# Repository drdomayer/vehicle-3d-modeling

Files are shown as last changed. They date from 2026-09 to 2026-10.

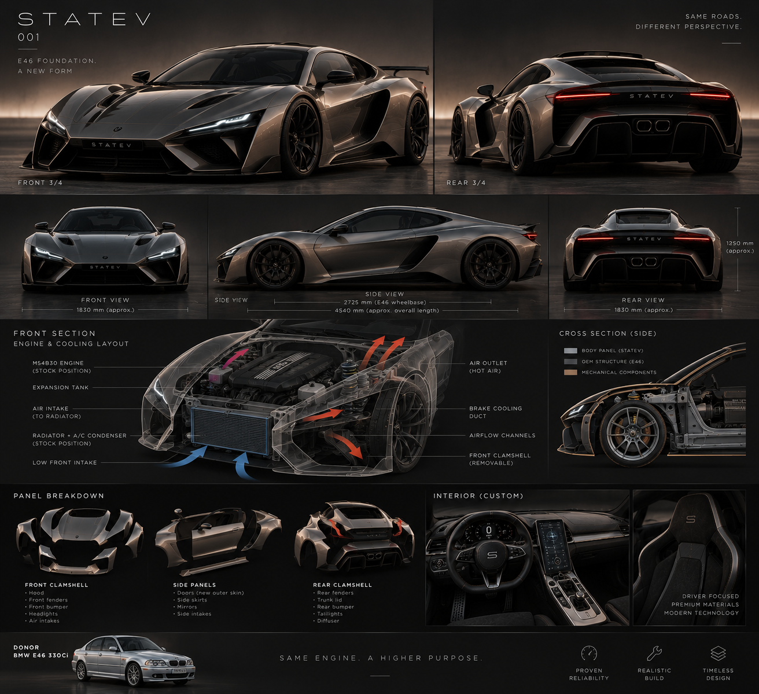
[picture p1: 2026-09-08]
07_PRESENTATION/references/ref-01-e46-supercar-concept-REJECTED-donor.png

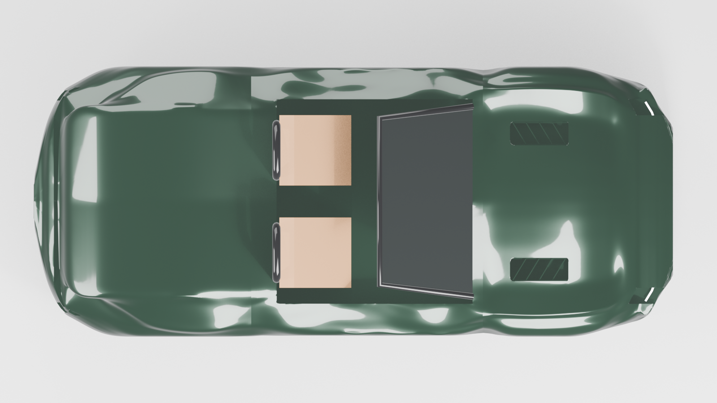
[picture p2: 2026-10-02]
04_ENGINEERING/statev_v01/review/rv_glossy_clean_top.png

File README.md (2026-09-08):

# vehicle-3d-modeling — STATEV 001

Boutique one-off sports car: new composite body + interior on a Porsche Boxster 986 base.

Start here:
1. `CLAUDE.md` — project memory (decisions, constraints, status). Claude Code reads it automatically.
2. `docs/` — brief, hardpoints, design direction, lighting/legal, manufacturing, budget, roadmap, tools, decision log.
3. `07_PRESENTATION/references/` — renders. `CHOSEN` = target, `REJECTED` = history.
4. `01_CAD/scripts/cage_986.py` — regenerable hardpoint cage for Blender.

Folders:
```
00_SCAN/          scans of the donor (raw, cleaned)
01_CAD/           scripts, STEP/IGES exports
02_DESIGN/        .blend files: exterior / interior / lighting
03_PRINT/         STL/3MF split for the printer + exploded-view PDFs
04_ENGINEERING/   clearance, tyre envelope, roof fold path, lamp positions
05_MOULD/         (only if a kit is made)
06_COMPOSITE/     layup notes, materials
07_PRESENTATION/  references, renders, branding
docs/             project documentation
```

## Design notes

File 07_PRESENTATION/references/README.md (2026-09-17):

# Reference renders (AI-generated, ChatGPT)

| File | What | Status |
|---|---|---|
| ref-01-e46-supercar-concept-REJECTED-donor.png | First STATEV 001 infographic on a claimed BMW E46 base. Mid-engine Huracán-type silhouette — impossible on E46. Kept for design language (front mask, light blade, panel breakdown, interior direction) | donor REJECTED, look = inspiration only |
| ref-02-z4-e86-front-engine-gt-REJECTED.jpeg | Front-engine GT on BMW Z4 E86 with Koenigsegg-inspired rear. Owner: "too Z4, no individuality" | REJECTED |
| ref-03-986-roadster-v1.png | First 986-based STATEV 001, soft surfacing | superseded ("boring") |
| ref-04-986-roadster-v2-soft-top-closed.png | v1 with closed soft top and raised deck | superseded; useful for the deck/roof integration idea |
| ref-05-986-futuristic-v3-CHOSEN.png | Radical futuristic direction (Czinger/Zenvo/Gemera language) on 986 hardpoints | superseded as the measuring target by ref-09 |
| ref-09-statev-001-four-view-CURRENT-TARGET.png | Four-view set of the same car — side, top, front, rear, plus three detail close-ups. Asked for in docs/18 | **CURRENT TARGET.** Side and top are measurable; front and rear are NOT — they show the cockpit interior, so the camera is above the car and their heights are foreshortened |

Rules: numbers in AI infographics are invented — ignore them. Renders show
wheels/clearance that are not road legal; the cage script has the real values.

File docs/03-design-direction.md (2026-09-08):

# 03 — Design direction

Референция: `07_PRESENTATION/references/ref-05-986-futuristic-v3-CHOSEN.png`.
Всички други рендери са история или отхвърлени варианти — виж README там.

## Език

Радикално футуристичен hypercar език: Czinger 21C, Zenvo Aurora, Koenigsegg
Gemera, Aston Martin Valkyrie. Не retro, не Porsche-подобно, без меки
повърхности. Собствен STATEV signature — не копие на никоя марка.

## Елементи (от ref-05)

**Отпред**
- Изключително нисък wedge нос; тънка светеща линия по цялата ширина (DRL) над
  голяма отворена уста към радиаторите.
- Плаващи предни калници с отворен канал зад всяко колело (изход на горещ въздух
  от радиаторите — функционален).
- Сплитер с вертикални елементи.

**Отстрани**
- Дълбок канал, врязан във вратата, който води към функционалния intake пред
  задното колело, с вертикално острие (blade).
- Наслоени панели с видимо "негативно пространство" между тях.
- Прагове със стъпка и черен долен канал.

**Отзад**
- Две високи аеро перки зад roll hoops вместо меки гърбици; преливат в
  повдигнат deck с открити ламели над двигателя.
- Затвореният мек покрив ляга между перките.
- Отворена задна структура: тънка обвивка над видим дифузьорен тунел, централен
  двоен ауспух високо в опашката, ултратънки L-образни светлинни остриета.

**Общо**
- Тъмно металик зелено, бронзови 19" джанти с реална странична стена на гумата,
  тан кожа, клирънс 120 mm.
- Всеки отвор е функционален. Без декоративни вентилации.

## Покрив и deck — правила

- Мекият покрив остава OEM механизъм. Не се пипа.
- Deck-ът се вдига/удължава така, че линията стъкло → покрив → задно стъкло →
  deck е една непрекъсната наклонена линия без стъпало, когато покривът е
  затворен.
- Deck-ът остава под долния ръб на задното стъкло на покрива (видимост).
- Всичко зад roll hoops се отваря или е част от капака (достъп до двигателя).
- Пътят на сгъване на покрива и clamshell-а се проверяват в CAD преди дизайн на
  deck-а.

## Правила за фуги

Ръбовете на новите панели лягат само върху съществуващи линии: фуга на
вратата, долен ръб на прага, отвор на стопа, фуга на задния капак, ръб под
roll-hoop капака. Където няма естествена фуга (горен ръб на рамото) — flush
секция с изрязана OEM обшивка и фланец.

## Как се прави рендер за референция (ChatGPT/Gemini)

Референция [ref-05] + 986 профил. Винаги: "mid-engine, cabin far forward,
keep windshield frame/rake, twin roll hoops, door cut lines, wheel centres,
wheelbase 2415 mm, side intake ahead of rear wheel functional, 19-inch wheels
with realistic sidewall, 120 mm ground clearance, no text overlays". Първо
профил, после 3/4. Числата в AI инфографиките са измислени — игнорирай ги.

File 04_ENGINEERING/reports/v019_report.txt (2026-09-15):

STATEV 001 — v019. One parameter changed from v018: REAR_UNDERCUT_FIELD.xb 3150 -> 2950.
v018 kept as the rollback baseline, byte-identical. Nothing frozen. Nothing committed at the time
this file was written.

=== THE SELECTION ==========================================================
xb = 2950 was chosen from a controlled A/B/C experiment run on the exact v018 baseline, in which
xb was the ONLY parameter that differed between variants. depth 108, x0 2260, xa 2560, x1 3400,
trans 72 and the edge table were identical in every variant and are identical in v019.

  A  xb 3050  REJECTED — the visual change against v018 was not enough to justify a change at all.
  B  xb 2950  SELECTED.
  C  xb 2850  REJECTED — the release became unnecessarily aggressive: the largest station-to-station
              change went to 58 mm against 50 in v018 itself, at specX 2965..3060.

2950 IS A VISUAL AND DESIGN SELECTION, NOT AN ENGINEERING-DERIVED VALUE. It was picked by looking
at rendered views, not calculated from anything. This is stated plainly so that no later session
treats it as a derived figure.

The only engineering anchors in this region are:
  rear wheel arch ends   specX 2780   (365 mm cylinder on the rear axle at 2415)
  diffuser tunnel starts specX 3145   (DIFFUSER_TUNNEL in statev_skeleton.py)
All three candidate values lay between those two anchors. Nothing in the packaging distinguishes
them; only the eye does.

Also recorded, because it was tested and disproved rather than assumed: xa is a DEAD LEVER for this
shape. Moving it from 2560 to 2780 changed the measured undercut by at most 1 mm at every station,
because between those two stations the undercut band sits inside the rear wheel arch aperture,
where the body has already been cut away. The earlier claim that the plateau was problematic for
starting inside the arch is withdrawn.

=== WHAT CHANGED ===========================================================
  undercut depth, same stations as the v018 report
    specX     2775   2870   2965   3060   3155   3250   3345
    v018       274    287    287    267    250    227    177
    v019       274    287    286    258    215    169    170
    change       0      0     -1     -9    -35    -58     -7

  Peak preserved: 287.3 mm at specX 2870, unchanged. The depth immediately behind the rear wheel is
  exactly as it was; only the release is earlier.
  Largest station-to-station change 46.5 mm, against 50 in v018 — the transition is smoother than
  the one it replaces, not sharper. No new step or discontinuity.

=== WHAT DID NOT CHANGE ====================================================
  length 4370.0      width 1849.438      floor 120.0      crown 996.451
  wheelbase 2415     track 1465 / 1528   glass 970 / 1255
  hoops Z 1235 at specX 1760             door shut lines specX 440 / 1635
  STATEV_WHEEL_F_L/R  specX 0     Y +-732.5  Z 323.5
  STATEV_WHEEL_R_L/R  specX 2415  Y +-764.0  Z 337.5
  faces 8899 (identical)   volume 3.906934 -> 3.911282 m3

  rear silhouette, crown line
    specX   2000   2200   2400   2600   2800   3000   3200   3420
    v018   967.2  993.2  989.6  938.2  858.3  759.4  642.4  513.1
    v019   967.2  993.2  989.6  938.2  858.3  759.4  642.5  513.1
  Unchanged to within rounding. The silhouette is not touched by this change and cannot be: the
  slab-tail fault corrected in v015 lived in the crown line, and the crown line is identical.

  Untouched and explicitly out of scope for this pass: fender, cabin, beltline, hood, door channel,
  nose, deck edge, wheel geometry, every locked dimension. No new field, no new mechanism, no new
  boolean — still six cut FEATURES (cabin, four wheel arches, nose mouth), which is seven
  boolean OPERATIONS because the nose mouth is mirrored. Unchanged from v018.

=== HOW v019 WAS PRODUCED ==================================================
statev_master_volumes.py carries xb = 2950 and v019 was rebuilt by executing that file directly
against the v018 baseline opened from disk. Not an in-memory substitution, and not a copy of the
experiment.

Verified rather than asserted: 9959 vertices, 8899 faces, volume 3.911282 m3, and a sorted-vertex
SHA-256 of 8a29a19de3ae440f58d5f578341cd95ad54e25eac148f5b3043e1296b20fe265 — identical to the
validated xb=2950 experiment. v019 is regenerable from source, as the project rule requires.

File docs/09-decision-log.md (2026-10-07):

# 09 — Decision log

Формат: дата — решение — причина. Добавяй отгоре. Не трий стари редове.

- 2026-10-07 (2) — **v081: окото по ref-09 — отвор през наклона, рамка-плоча, прозрачен капак
  P69/P70.** Отблизо окото беше хаос от блокове. Причината е рязането: кутия по X на средната
  височина срещу скос от ~50° отваря само лента, а лещата стои на 109 mm зад кожата. Решение:
  режещото тяло минава от въздуха до 10 mm зад горния ръб, рамките са плоча 20 mm под кожата,
  отпред има прозрачен капак в кожата. Регистър 54 → 56 части. Капакът е **CONDITIONAL** с две
  причини: предната греда и **законов въпрос — капак пред E-маркиран модул**, който се решава от
  техническата служба (`docs/04`). Без капака окото остава отворено и чисто. Булевите за рамките
  са MANIFOLD: EXACT губеше външната рамка и режеше асиметрично. R48 видимост 45° навън
  55 → 73 %. 60/60 файла чисти, одит 12 / 28 / 16 / 0. `docs/14` AD.

- 2026-10-07 — **v080 (3): колелата и колесните ниши в рендера** (контекст, каросерията не е пипана).
  (1) **Джантата по ref-09:** 10 спици, всяка се разцепва на две рамена от средата до ръба, вдлъбнато
  лице (главината 30 mm навътре от ръба); бяха прави пръти и четяха като спици на колело. Бронзът по-
  тъмен (0.30/0.17/0.07, metallic 1.0) — старият огледално отразяваше бялото студио и излизаше бледо-
  сив. Апаратът с размера на шестбуталния от рендера (~170 × 90 mm). (2) **Колесни ниши (донорски):**
  каросерията е отворена черупка, затова през всяка арка се виждаше кухото тяло — в предния 3/4 кадър
  кафявите седалки стояха над предната гума. Тъмен полуцилиндър над всяка гума (r гума + 45 mm,
  |Y| 440..905) със затваряща вътрешна стена. Намерено с лъч от камерата, не по око.

- 2026-10-06 (18) — **v080 (2): кабината в рендера — седалки, табло, стъклото стъпва на кожата.**
  Всичко е контекст (донорско или интериор, отделна работа); геометрията на каросерията не е пипана.
  (1) Седалките бяха плочи на Z 650, 350 mm над пода на ваната — сега спортни седалки по страничен
  профил (възглавница 440 → 405, облегалка с вградена опора за глава до 1080, ребра 55 mm), пред
  преградата и дъгите. (2) **Долният ръб на стъклото беше права линия на Z 968** — височината на
  cowl-а само по осевата линия; кожата под него пада до ~870 при |Y| 600 (мерено с лъч), така че
  стъклото висеше на ~100 mm над калниците с кабината отдолу. Сега ръбът следва кожата при spec X 420
  през 50 mm, рамката също. (3) Табло — тъмен клин зад задния ръб на кожата (450..720, Z 650..860,
  |Y| 630), под кожата навсякъде, където се застъпват.

- 2026-10-06 (17) — **v080: окото — рамките без стълбица, лещата в рендера, черното само в окото.**
  (1) Височините на рамките P65–P68 се взимаха от 25 проби на станция, затова горният и долният им
  ръб скачаха с 1/24 от височината между станции — стълбица в гланца. Краищата вече се уточняват с
  бисекция до истинската граница. Видимостта по R48 непроменена (ос 100 %, 45° навън 55, 10° навътре
  91, 15° нагоре 100, 10° надолу 84 %), файловете растат с ~1 cm³; другите части не мърдат.
  (2) Hella модулът (купешки, E-маркиран) е контекст в рендера — леща r 45 в полиран пръстен; без нея
  окото беше празна черна кухина. (3) **Черното на окото по P01 беше и пред окото:** контурът се
  проверява в (|Y|, Z), а кутията му по X е −1000..−500 — носът при spec X ≈ −900 под вътрешния връх
  попадаше в контура и излизаше на назъбени черни петна. Режещото тяло заема само [дъно −60, дъно]
  по X; дъното се мери с лъч, в процепа на модула (|Y| 590..700) се интерполира. Два опита по пътя са
  отхвърлени с рендер: по-малък толеранс за стените и ограничение само отзад — нулев ефект, защото
  лицата бяха отпред; и сатен черно за окото — под горната светлина чете сиво и показва стълбицата.

- 2026-10-06 (16) — **v079 (3): накрайници на ауспуха и гуми в рендера.** Накрайниците са купешки
  (P35 оттеглен на 30 септ.), значи в рендера са контекст като седалките: две полирани тръби r 50/45
  в двата отвора Ø104 (Y ±65, Z 430), устието 5 mm навътре от кожата (spec X ~3400, мерено с лъч),
  150 mm дълбоки с тъмно дъно. Отзад ref-09 се чете от тези два пръстена; ние показвахме две дупки.
  Гумата: по-тъмна, по-груба, половин specular — в бялото студио четеше светлосива.

- 2026-10-06 (15) — **v079 (2): изгледът отгоре.** Три неща, които правеха плана бял там, където
  ref-09 е тъмен: (1) през среза на кабината се виждаше подът на студиото — добавена донорската вана
  като контекст (под Z 300, тунел, преградa зад седалките), като седалките; (2) решетката **P33 —
  carbon (сатен), не гланцово черно**: хоризонтални ламели под горна светлина са огледало и четяха
  бяло; (3) в изгледа отгоре горният софтбокс осветява, но не се вижда в отраженията — иначе капакът
  и deck-ът са бели листове. Геометрията не е мръднала.

- 2026-10-06 (14) — **v079: двуцветна предница и presentation рендер.** (1) **P01 под DRL канала е
  гланцово черно** — в ref-09 всичко под DRL линията (рамката на устата, фасетите, рамките на ъгловите
  входове) е черно, у нас беше зелено. Линията е долната устна на DRL канала (`DRL_Z` − 12 mm), тоест
  истински ръб, по който бояджията лепи лента, не линия върху гладка кожа. Записано като
  `FINISH_ZONES` в `panel_registry.py` (нова колона в BOM-а, видима в `docs/19`), рендерът я чете.
  Първият рендер даде **трион** от зелени зъби под DRL-а — тестът по центъра на лицето боядисва цели
  триъгълници от двете страни на линията; рендер-копието вече се реже по самата линия
  (`bisect_zones`, семплирано на 20 mm по PCHIP кривата). Файловете за печат не са пипани.
  (2) **`GLOSSY_PRESENT`** — режим с моделна студийна светлина (горна софтбокс, две странични ленти,
  преден запълващ), под и свят разделени по camera ray, за листове, които се показват на хора;
  `rv_glossy_present_*.png` + `sheets/present/`. Геометрията не е мръднала.

- 2026-10-06 (13) — **v078: две решения по силовата структура, взети от мен по указание на
  собственика („вземи най-добрите решения").** (1) **Прорезът в калника се мести навън над гумата**
  (|Y| 385..545 → 615..755): на старото място целият стоеше над опората на амортисьора и не можеше
  да е нищо освен фалшив отвор (заключено „без фалшиви отвори"); новото място е функционално и
  встрани от опората. Цена: ~200 mm встрани от ref-09. (2) **Предната греда: нова метална, от
  инженер, над устата** — оригиналната така или иначе не се побира в носа, който е 57 mm по-къс;
  обвивка `CRASH_BEAM_NEW` (−925..−875, |Y| ≤ 430, Z 450..550), затворена. Зоната „front strut top"
  махната от одита (над опората вече нищо не се реже). Одит 12 / 26 / 16 / 0; `docs/13` 12 части.
  `docs/14` AB.

- 2026-10-06 (12) — **v077: височините на гасителите — отпред конфликтът се потвърждава, отзад
  вероятно няма.** От страничните изгледи (стр. 5-11: 2.219 mm/px; стр. 5-13: 2.569, по отпечатаното
  485.5), спрямо допуснатото Z 160 на точките за крик, ±40: **предните гасители P1 на Z ~411** — вътре
  във височината на устата (220..430) и ъгловите входове (240..462); **задните P20 на Z ~481** — прорезът
  на стопа и корпусите (от 593) и значката (от 585) са ~100 над тях, гнездото за номер (до 372) и
  тунелът (≤ 410) ~70..110 под тях. Отзад остава SCAN (височината на самата греда не е известна), но
  вече с числа. Добавена и **задната опора на амортисьора P15**: 998.2 mm L–R публикувано, spec X
  ~2313 и Z ~802 по мащаб; кожата над нея (лъч отгоре) е на Z 1011, +206 mm въздух — нашият deck не я
  притиска. Първото мерене взимаше най-високия връх наоколо; сменено с лъч точно над точката.

- 2026-10-06 (11) — **v076: горната опора на предния амортисьор (структурна точка P6) е под прореза в
  калника.** Нищо за P6 не е отпечатано; трите координати са снети по мащаба на стр. 5-11 (отгоре
  3.817 mm/px, отстрани 2.219 mm/px, калибриран така, че P1–P8 съвпада с изгледа отгоре; P5–P8 го
  потвърждава до 1 %): **spec X ≈ −40 ± 30, |Y| ≈ 500 ± 15, Z ≈ 736 ± 40** (Z е спрямо допуснатото
  Z 160 на P8). Прорезът е spec X −250..180, |Y| 375..560, изрязан до Z 690 — опората е вътре в него.
  Освен твърдо ограничение 4, това е и „без фалшиви отвори": над опората прорезът не може да стигне
  арката. Формата не е пипана (дизайнерско решение по ref-09 — да се плитка или да се мести навън,
  над гумата). Одит: зоната на структурите вече има и |Y| обхват и причините се събират (капакът P02
  излизаше заради опората само по X и губеше измерената си причина cowl_x). **10 PROCEED**; P05/P06
  → CONDITIONAL. `docs/13`: 10 части; `docs/20`: мерене A7.

- 2026-10-06 (10) — **`docs/20`: какво да се измери с ролетка на истинска 986.** Предницата и
  задницата чакат гредите, а за тях не трябва скан — 16 числа (A1–A6, B1–B4, C1–C4), всяко с
  метод и с това какво решава в модела; снимка с ролетката за всяко, двойно мерене.

- 2026-10-06 (9) — **v075: задната силова структура — същото като отпред, но с присъда SCAN.**
  Структурна точка P20 (manual, ≠ нашия панел P20) = заден монтаж на задните гасители: 824 ± 1.5 mm
  L–R **публикувано**; надлъжно по мащаба на стр. 5-13 (калибриран по 485.5 ± 2, 1.889 mm/px) по два
  пътя — от P11: 2953, от P16 (= P5 + 2700 ≈ 2408, почти задната ос): 2990 → **spec X ≈ 2970 ± 40**.
  Лицето на 986 отзад ~3308, нашата опашка 3420. Отворите ни отзад са **между** P20 и лицето, не зад
  гасителите — затова SCAN (зависи от височината на гредата), не CHECK като отпред. Одит **25 → 12
  PROCEED**: P21, P22, P26/P27, P44–P47, P56/P57, P58/P59, P60 → CONDITIONAL. `docs/13`: 12 части за
  котиране, списъкът поименно. Тялото непроменено.

- 2026-10-06 (8) — **v074: предната силова структура влезе в модела — и предницата излезе от пакета за
  котиране.** Workshop manual Group 5, стр. 5-11: P1 = заден монтаж на предните гасители на удара
  (M8). **Публикувано:** 800 ± 1.5 mm между лявата и дясната. **Не е оразмерено надлъжно:** снето по
  мащаба на чертежа (калибриран по 507 ± 1.5 между P4 и P7, 1.555 mm/px) — P1 → P8 = 1225 mm, тоест
  **spec X ≈ −875 ± 40**. Нашият нос е на −950; **устата стига до −815, ъгловите входове до −745** —
  зад P1 дори при +40 края на лентата. Гредата е между P1 и лицето на 986 на височина, която никой
  не е мерил; ако е на височината на устата (Z 220..430), устата минава през нея (твърдо
  ограничение 4). Добавени: P01 в клетката, зона „front crash structure" в одита (проверява се
  преди измерената експозиция, която не може да я види), ред в `check_donor_fit`. **Одит 35 → 25
  PROCEED**: P01, P28/P41, P43, P54/P55, P61/P62, P65/P66 → CONDITIONAL (последните две — само по X;
  стоят на височината на фара и вероятно минават над гредата). `docs/13`: 25 части за котиране.
  Тялото не е пипано.

- 2026-10-06 (7) — **v073: законовото осветление получи обвивки и проверка.** Ревю по твърдо
  ограничение 5: в модела имаше място само за фара и задната лента; мигачи отпред и отстрани,
  трети стоп, заден ход, противомъгла, светлоотражатели и лампа за номера нямаха обвивка, значи
  нищо не ги проверяваше. Добавени седем обвивки на измерената кожа и `legal_geometry()` в
  `check_lighting.py` (височини, разстояние до външния ръб, разстояние между двойката, от носа,
  от стоповете). **Всички минават** — стойностите на R48 са по памет и чакат техническата служба.
  Най-тясно: третият стоп, 9 mm над 850, върху капак, който чака скана на покрива. Тялото
  непроменено. `docs/04` има таблица.

- 2026-10-06 (6) — **Листът за пробния печат P39 казваше две неща, които не са верни за P39.**
  (1) Че изпитва фугата между секции — от 26 септември P39 е **един** файл; сега листът казва
  изрично, че този печат **не** я изпитва (тя се изпитва само ако плотът на печатницата наложи
  рязане), и етап 2 се пропуска. (2) Че изпитва устната на вратата (67°) и гребена (55°) — те не са
  на P39. Сега ръбовете се мерят от самия файл: **7 външни ръба над 20°, най-острият 48°** (ръбът на
  прага, проектиран 49.6°). Първото мерене даде 96° — ръбът на черупката минаваше радиалния тест;
  лицата до вътрешната стена вече не се броят. README вече не казва „three sections“.

- 2026-10-06 (5) — **`docs/13` обновен за изпращане; геометрията непроменена.** Нов раздел „Какво
  им пращаш" (35 части за котиране, ~7.2 m², ~27 kg ядро при временната стена; цели панели; P39
  първо), стойностите, взети след 14 септември (фланец 30 + 1 mm, цели панели, езиче 20 mm вместо
  ключове), и нови въпроси 40–45: видим карбон върху печатно ядро (17 части), гланцово черно,
  ASA до лампите, и **раздел към бояджийско-тенекеджийския сервиз** — рязането на OEM четвъртта за
  шахтата, фланецът на четвъртта, монтажът на огледалото. Поправена грешна препратка в генерирания
  README и `fit_test`: фугата е **Q14**, не Q16 (16 е монтаж); допускът е Q13/Q29.

- 2026-10-06 (4) — **v072: огледалата P37/P38 — купешко огледало с печатна капачка, по ref-09
  (решение на собственика).** BLOCKED → SHAPE ONLY; **одит BLOCKED 0 за първи път** (35/3/16/0), и
  всички 54 части имат файл. Височината е спрямо нашия горен ръб на вратата (ref-09 не се калибрира
  по височина); по Y главата е навън от страничното стъкло (|Y| 730..880), не на рендера (639..804) —
  допускане до скана. 58/58 файла чисти, нищо не е регресирало. Откат v071.

- 2026-10-06 (3) — **Ръстът на `.blend` (1.42 → 2.54 MB) обяснен и премахнат; геометрията непокътната.**
  `exploded_assembly.py` създаваше нов материал `MX_Pxx` при всеки пуск; 18 пуска оставиха 916, всеки
  „в употреба" от осиротялото копие на меша от предния пуск, затова Blender ги записва (самите
  сираци — 9690 меша, 862 криви — не се записват). Сега материалът се преизползва по име (същото в
  `render_panels.py`), сираците са изчистени, v071 презаписан: **1.60 MB**. Второ пускане не добавя
  нищо (52 `MX_` материала, по един на част).

- 2026-10-06 (2) — **v071: устната на шахтата** — фаска 25 × 15 mm по предния ръб, следва
  кожата. Реже както е замислено (13 mm на ръба, 0 на 25 mm), но в гланца е слаба: вливането в
  ref-09 е широк канал по вратата, тоест повърхност, не фаска. 56/56 чисти, нищо не е регресирало.
  `waviness_check` прекъсва профилите с 30 mm около отворите в X–Z (беше 10). Откат v070.

- 2026-10-06 — **v070: лопатката P13/P14 на наклонения преден ръб на шахтата**, по ref-09
  (беше в стария отвор от v024, 200 mm по-назад). 16 mm при Y 876 — с 22 mm при 880 стърчеше
  3.3 mm в долината на канала на вратата. Въздух зад нея ≥ 4.1 mm. Скосената устна не е направена
  (иска друг тип резач). 56/56 файла чисти, нищо не е регресирало. Откат v069.

- 2026-10-05 (11) — **v069: страничната шахта — по решение на собственика се реже OEM четвъртта.**
  ref-09 калибриран по колелата: отворът е при spec X ~1730..1900, пред донорския. Рампа тип NACA,
  25 → 130 mm дълбока между 1735 и 1925, влива се в истинския отвор; наклонен преден ръб; дълбочината
  е SCAN REQUIRED. Нов вид джоб в картата — очертание в X–Z (`POCKETS_XZ`), защото наклоненият ръб
  не се описва в Y–Z. Рамката P11 1780..2300 → 1700..2170 (иначе три парчета). Защо шахтата спира на
  1925: при 1965 пресичаше границата SIDE/REAR и остави лицето на резача в тялото (ширина 2000).
  `check_donor_fit` и `waviness_check` изключват шахтата по име, с брой. 56/56 файла чисти, нищо не
  е регресирало. Откат v068.

- 2026-10-05 (10) — **Въглеродните части в гланца са сиви от осветлението, не от материала.**
  Проверено: P22/P28/P07/P44 получават `GLOSSY_CARBON` (основа 0.018); A/B metallic 0.3 / roughness
  0.32 срещу 0 / 0.15 дава един и същ сив кадър. Повърхностите гледат надолу/настрани към светлия
  под и при плъзгащ ъгъл отразяват почти всичко. В ref-09 подът под колата е в сянка. Осветлението
  не е пипано — това би било нагласяне на картинката, не на колата. Геометрията непроменена (v068).
  В `glossy_renders.py` остават ключовете `GLOSSY_CARBON_MR` и `GLOSSY_DEBUG` за такива проверки.

- 2026-10-05 (9) — **v068: DRL линията продължава в окото до върха му.** Жлеб R7 по долния ръб на
  външната вложка P67/P68, Y 778..846, ос 5 mm над ръба. Отпред линията вече минава под фаровете и в
  краищата се качва до върха на окото, както в ref-09. Между края в кожата (ъгъла) и началото във
  вложката остава прекъсване, видимо в 3/4 изглед. Вложките остават затворени тела, 58/58 файла
  чисти, видимостта по R48 непроменена, нищо не е регресирало. Откат v067.

- 2026-10-05 (8) — **v067: DRL-ът под лещата и нагоре до ръба на ъгъла; ъгловият вход 18 mm по-нисък.**
  Ревю срещу ref-09: линията на светлината свършваше вътре в окото, пред лещата на фара. Сега минава
  под нея на Z 493 и се качва под долния ръб на окото до ъгъла (Y 776, Z 546). До външния връх на
  окото не стига — под гребена кожата се прибира и каналът или зигзагира, или излиза във въздуха
  (измерено). За да има място под лещата, горният ръб на ъгловия вход 480 → 462. Два дефекта по пътя:
  целта на точките върху самото лице сложи оста на ръба към капака (носът 4377); оста точно в
  равнината на лицето провали EXACT разликата само вдясно (люспа 7 mm пред носа, 4380) → ос 0.3 mm
  навън по нормалата. Сглобка 4373 × 1850.0, 58/58 файла чисти, нищо не е регресирало. Откат v066.

- 2026-10-05 (7) — **v066: рамката на окото (P65–P68) и свързаният сплитер.** Затворена рамка
  около модула **не е възможна**: геометричната видимост по R48 (45/10/15/10°) е законово
  изискване, а пред лещата конусът ѝ запълва цялата височина на окото. Затова рамката е обемът на
  окото минус този конус — две черни части на страна (връх навътре, острие навън), и видимостта е
  измерена еднаква с и без тях (55/92/100/84 %). Ново: `check_lighting.py` мери видимостта при всяко
  пускане. Три дефекта по пътя: лицето от една точка на станция стърчеше 44 mm (кожата завива към
  капака) → профил по кожата на 9 височини; над гребена на ъгъла пак 5 mm → пресичане с
  неотрязаното тяло; игла от булевата операция → свиване на изродените лица. Сплитерът: правилото за
  пода хващаше долния ръб на фаската (гледа напред, подът никога) — P28/P41 едно парче. Регистър
  50 → **54**, 58/58 файла чисти, `check_goal`: нищо не е регресирало. Откат v065.

- 2026-10-05 (6) — **v065: окото на фара.** ref-09 отпред: фарът е дълъг наклонен клин от ъгъла
  навън и нагоре по ръба на калника, над DRL линията; при нас беше само прорезът на модула. Черна
  вдлъбнатина 40 mm, Y 520..850, висока колкото Hella 90 mm модулът иска (Z 505..627), изтъняваща
  до 28 mm навън — **не е 55 mm като в рендера**, защото модулът не се пипа и не се покрива.
  Три поправки по пътя, всяка измерена: (1) рязането по нормалата на повърхността наклоняваше
  стените до 28 mm встрани от контура и P01 стана **5 парчета** → режа се по X; (2) моят полигон
  `X_EYE` беше **вдлъбнат** при (820, 592), а `in_poly` е тест за изпъкнал — разделен на три; (3) P01
  излезе с 3 отворени ръба във файла (триъгълник 0.003 mm² на мястото, където стената на прореза на
  лампата среща пода на окото на същото Z) → `tidy_for_export` затваря 3-ръбни дупки под
  `FLAP_MAX_MM2`. Станциите сгъстени до 15 mm, защото с 7 горният ръб в гланца излизаше насечен.
  **`panel_extract` вече брои парчета като производството** (по ръбове, остатък под 1/10 се
  брои, не се печата) — доставчикът виждаше „3 парчета“ срещу файл от едно. Новото броене откри
  стара находка: **сплитерът P28/P41 е устна и плоскост, допрени в един връх** (Y 530, X ~−900);
  файлът е едно парче само защото стената ги слепва. Не е поправено. 54/54 файла чисти, сглобка
  4373 × 1850.0, 100% в 8 mm, `check_goal`: нищо не е регресирало. Откат v064.

- 2026-10-05 (5) — **v064: ъгловати гърбици и острият гребен на калника вече се вижда.**
  Гърбиците: плоско горнище до 2010 и прав скат до 2185, сечение експонента 6, ширина до края —
  по ref-09 отстрани. Гребенът: по проект е 74°, мешът показваше 46°, закотвен — **70°**; edge
  test го мери за първи път, записан като изключение по решение на собственика (G1 по `docs/16`).
  **A/B, което не помогна:** ъгълът на горнището на стената на хълбока е 14.8° по проект при
  всяка от четирите комбинации ease/hold — тези параметри управляват наклона на стената, не ъгъла.
  **Два дефекта по пътя:** (1) левата гърбица излезе без горнище — второто изваждане вървеше
  върху черупка, вече отворена отдолу, а EXACT върху отворено тяло е неопределен; редът е обърнат
  (първо рязане отдолу, после кухина). (2) P12 с 3 отворени ръба — притискането към ±925 сплеска
  един триъгълник в права, а почистването го изтри; сега такива се свиват
  (`dissolve_degenerate`), не се трият. `check_goal`: нищо не е регресирало (surf_x 3.63, задният
  изглед 0.08); 54/54 чисти; сглобка 100% в 8 mm. Откат v063.

- 2026-10-05 (4) — **v063: гърбиците зад седалките (P63/P64, shape only) и диагоналният гребен на
  хълбока.** Собственикът изрично поиска гърбиците, затова са построени, въпреки че са в обема на
  сгъване на покрива: черупки 4 mm от дъгите до решетката, горнище 1175 → 985, ширина 450 —
  прецедент Boxster Spyder (гърбиците са на капака на гюрука); чакат скан S2. Гребенът на хълбока
  върви диагонално в план, както в ref-09 отгоре, завъртян около задната ос (при първия опит с
  изместване и при оста задният изглед регресира 0.08 → 0.12; със завъртането 0.07). Регистър 48 →
  **50**. `check_goal`: нищо не е регресирало (заден силует 21, заден изглед 0.07, surf_x 3.67).
  Мярката за вълни отгоре расте (1.24 mm RMS), защото профилите на постоянно Y пресичат два нови
  ръба по замисъл — опашката на гърбицата и диагоналния гребен — не вълни. 54/54 файла чисти,
  сглобка 100% в 8 mm. Откат v062.

- 2026-10-05 (3) — **v062: задните калници без седло, платната зад седалките оттеглени; две
  хипотези за вълните опровергани с числа.** Собственикът: „отгоре нещо не изглежда, както и
  страните зад седалките и задните калници". **Калниците:** седло от 40 mm в рамото при specX
  ~1900, между края на `DOOR_OUT` (1720) и началото на стената на хълбока (1900) — стената вече
  тръгва от 1550 на височината на горнището на вратата; седлото изчезна (`docs/14` T).
  **Зад седалките:** P17/P18 (дъски 40 × 950 mm на Y 705) не съвпадаха с нито един изглед на ref-09,
  където там има гърбици — в обема на сгъване на покрива, чакат скан S2 (`docs/14` J оттеглено,
  регистър 50 → 48). **Опровергано:** донорската таблица има шум ±5 mm и кожата на канала го
  копира, но билатерално изглаждане (без недостиг спрямо суровата таблица) свали вълните само
  0.85 → 0.83 mm — изключено, `DONOR_SMOOTH = False`, кодът остава. **Мерки:** `check_goal` —
  нищо не е регресирало (заден силует 22 → 21, surf_x 4.00 → 3.80, surf_z 7.31 → 7.42 в допуск);
  въздух до донора непроменен (+16/+22/+30); 52/52 файла чисти; сглобка 100% в 8 mm. Откат v061.

- 2026-10-05 (2) — **v061: вълните са измерени; изглаждането на файловете (вариант а) е опитано
  и ОТХВЪРЛЕНО; дупката под калника е затворена.** Нов инструмент `waviness_check.py`: профили по
  сглобените файлове през 10 mm, остатък от локална квадратична крива на 300 mm прозорец (кривината
  на колата не влиза, къса вълна влиза с височината си). **Файлове 0.85 mm RMS, мастер 0.85 mm** —
  вълните са на лофта, не на веригата. Изглаждане на файловете: `smooth_laplacian_vert` със
  запазване на обема върху отворени черупки е нестабилно (сглобката 93 m дълга); `smooth_vert`
  ×20 даде **0.85 → 0.82 mm** срещу **медиана 0.15 → 0.36 mm** отклонение от проекта — гаси вълни
  ~40 mm, а буците в гланца са **300–900 mm** (на 600/900 mm прозорец остатъкът е 2.5/4.6 mm RMS)
  и част от тях са проектните гаусови полета (калник, хълбок). Изключено (`PROD_FAIR_ITER = 0`),
  кодът остава за A/B. Изводът: вълните се оправят само в самата повърхност (вариант б). **Дупката
  24 mm под P03:** лентата отдолу, обърната към пътя, беше наполовина под, наполовина кожа, и
  островите отпадаха; подът вече е и `nz < −0.85` под Z 145 (без дифузьора). Най-лоша точка в
  сглобката **24 → 4.1 mm**, 100% в 8 mm. 54/54 чисти, `check_goal` — нищо не е мръднало. Откат v060.

- 2026-10-05 — **v060: висящите неща, които не чакат скан, печатница или постер.** Собственикът:
  „направи всички висящи неща". **Направено:** фасети на маската (клиновете между устата и
  ъгловите входове обърнати навътре от равнина); крайни пластини на сплитера P61/P62; черна лента
  между стоповете и значка STATEV P60 (печатна, букви 4 mm над подложка); **P23 оттеглен** —
  ducktail-ът е самият профил на опашката, не част; **`docs/14` I приет (A)**. Регистър 48 → **50**.
  **По пътя:** фасетата с ъгли в ъглите на джобовете прищипа P01 на 3 файла — преначертана с
  пресичания на ≥ 21 mm от ъглите, P01 отново 1 файл; значката излезе 216 × 40 и е уголемена до
  284 × 48. `assembly_check.py` вече казва КЪДЕ са най-лошите точки — и намери **стара** дупка от
  24 mm в долния ръб на P03 пред предната арка (Z 120, specX −309, Y 693), същата и в предишния
  комит: не е от тази версия, записана е за поправка. **Не е направено, и защо:** огледалата — няма
  позиция никъде, донорска е; deck/капак/платна — скан S2; печатницата — `docs/13`; постерът — не е
  в репото; голямата страничната вдлъбнатина — иска рязане на плътния OEM панел пред донорския
  отвор; вълните — скулптиране, следващата задача. 54/54 файла чисти, одит 31/3/14/2, `check_goal`
  — нищо не е мръднало. Откат v059.

- 2026-10-03 (2) — **v059: шест перки в дифузьора, шест ламели в калника; крайни пластини на
  сплитера — НЕ.** Перките: в ref-09 са по три от всяка страна на ауспусите, при нас бяха по две.
  Първият опит (трета двойка на Y ±490) падна на измерването: тунелът е плосък само до |Y| ~400–450,
  на 490 подът е с 23 mm по-ниско още при 3000. Трите са преразпределени равномерно в плоския тунел —
  **120 / 255 / 390**; крайната (нови **P58/P59**) стига до 3250, докъдето подът на ръба ѝ е в 3 mm
  от централния — отчетено от тялото. Ламелите в отвора на калника: 4 → **6** при стъпка 54, първата
  и последната на старите места (гребенът остава в прореза). **Крайни пластини на сплитера не са
  правени:** биха стърчали от лицето — точно видът елемент, който беше оттеглен като „паразитен" на
  29 септ.; ако ги искаш, кажи. Регистър 46 → **48**, 51/51 файла чисти, одит 28/3/14/3, нищо не е
  мръднало по `check_goal`. Откат v058.

- 2026-10-03 — **v058: шестоъгълните решетки — мрежата е печатна.** Собственикът: „продължи с
  брони, решетки". Решен е отвореният въпрос (б) в полза на печат: всяка решетка е една плоска плоча
  с непрекъсната рамка (`hex_grille()` — дупка само където цял шестоъгълник се побира в рамката),
  носена от стените на джоба. Устата: пълнеж на рамката P43 (една част). Нови части **P54/P55**
  (ъглови входове, наклонени с фаската) и **P56/P57** (задни ъглови вентове); регистър 42 → **46**.
  Задните стърчаха 8 → 4 → 0 mm, докато външният им ръб не започна да следва кожата. Попътно:
  `supplier_package` се пускаше преди регистърът да запише BOM-а и отчиташе 42 части / 22 за
  котиране; пуснат след него — **46 / 26**. Резултат: 49 файла, **49/49 чисти**, всички едно парче,
  0 стърчащи, одит 26/3/14/3, сглобка 4373 × 1850.0; `check_goal` — нищо не е мръднало. Откат v057.

- 2026-10-02 (4) — **v057: задницата по ref-09 и три поправки във веригата за печат.**
  **Задницата:** фугата P21/P22 вдигната зад specX 3000 — 500 около ауспусите, 410 до |Y| 660, 330
  навън (`diffuser_top_at()`); черната долна част вече заема долните ~37% от височината на дъгите
  като в рендера. Стопът свети само навън от |Y| 430, с черна лента между тях. Тялото не е пипано.
  **Три намерени дефекта:** (1) `FLANGE_AT` държеше границата на сплитера като число 300, а v056 я
  премести на 194 — **фланецът на P01 към P28 тихо беше изчезнал** при 45/45 „чисти" файла; сега
  равнините се четат по име от картата. (2) Новите разрезни равнини, пуснати по цялата кола,
  разцепваха лица в джобовете отпред и отстрани (P01 на 2 парчета, P11/P12 на 3) — вече режат само
  зад фасадата. (3) **Изглаждането за печат запълваше отворите**: Catmull-Clark върху вдлъбнатия
  n-ъгълник около отвор слага точка в дупката; двата ауспуха Ø104 излизаха във файла ~80 mm и
  неправилни. Вдлъбнатите n-ъгълници над 6 страни се триангулират преди изглаждането, без онези,
  чиито диагонали вече са ръбове (иначе ръб с три лица → шипове до 2 m в P01). Измерено: ауспух
  r 51.9 при 52; два по-тесни опита паднаха на числата и са записани в кода.
  **Резултат:** 45/45 чисти, покритие 100%, ширина 1850.0, дължина на сглобката **4376 → 4373**
  (част от „+6 mm" е била същото изглаждане), медиана 0.15 mm; `check_goal` — нищо не е мръднало.
  Откат v056.

- 2026-10-02 (3) — **v056: задният капак и предната броня.** Собственикът: „задния капак е много
  различен, както и предната броня". **Задният капак липсваше изобщо:** P19/P42/P20 са BLOCKED на
  покрива и нямаха файлове, а лентата зад дъгите се водеше на P17, което от 29 септ. е острието —
  тоест и тя не беше в никой файл. Сега deck-ът и капакът излизат като SHAPE ONLY (височината не е
  пипана), капакът е с отвор specX 2210–2890 × ±385 и решетка-касетка **P33** (7 надлъжни ребра + 7
  напречни летви, прочетени от ref-09 отгоре и отзад), P20 е цвят на каросерията. **Отпред:**
  ъгловите входове с наклонен вътрешен ръб (Y 450 горе → 590 долу), сплитерът само устната
  (`splitter_top` 300 → 194), DRL-ът в рендера стои върху реалния канал (беше 60 mm вътре в носа),
  вътрешността на отворите е черна в рендера, изгледът отгоре е с носа наляво като ref-09.
  **Измерено:** покритие на кожата с файлове **85.7% → 100%**, 45 файла (26 + 19 shape-only),
  **45/45 чисти**, всички едно парче, сглобка 4376 × **1850.0**, медиана 0.15 mm, 100% в 8 mm,
  0 стърчащи елемента; силует/план/кривина/ръбове непроменени (`check_goal`). Одит 22/3/14/3.
  Записано в `docs/14` P. Откат v055.

- 2026-10-02 (2) — **цялата кола сглобена от файловете за печат и оцветена като рендера.**
  `glossy_renders.py` получи финален режим (`GLOSSY_FINAL`): Cycles, 41-те файла на местата им по
  `placement.json`, финиш по регистъра, остри ръбове над 35° (стената от 3 mm размазваше засенчването
  на всяка фуга), 19" джанти с 10 спици, спирачен диск и бронзов апарат, гума като пръстен, тъмна
  среда за тъмния металик, два „hero" ъгъла като постера. Листовете: `review/sheets/car/`.
  **Присъдата:** файловете са годни за печат и се сглобяват в колата (41/41 чисти, медиана 0.15 mm
  до проектната повърхност, 1850.0) — но колата **не изглежда като рендера** и причините са три вида:
  (1) пропорция — 19" джанти, клирънс 120 и донорът (заключени съзнателно; рендерът е на ~22"); (2)
  езикът на повърхностите — фасетите на маската, голямата вдлъбната врата и scoop-ът, тънкият хълбок,
  платната като плоски дъски; (3) гладкост — **измерено**: отклонение от гладка крива на 600 mm
  средно 0.4–2 mm, 90% под 1–4.6 mm, най-много 8.2 (горнище на калника) и 10.0 (горен ръб на вратата).
  Тъмният гланц показва 1–2 mm като ясна вълна; това е в обхвата на шпакловка и дълга дъска, с
  изключение на няколко места до 10 mm, които са за поправка в модела.

- 2026-10-02 — **v055: пълно ревю срещу рендера — стърчащи елементи 10 → 0, дифузьор като тунел,
  финиш по части, 41/41 файла чисти, и таблица панел по панел.** Собственикът: „ревю не само по обеми,
  а по форми, кривини, детайли, и да го довършим панел по панел, готов за 3D печат".
  **Инструменти:** `glossy_renders.py` вече дава и седемте изгледа на ref-09 (страна, отгоре, отпред,
  отзад, вход, маска, опашка), с финиш по части (`FINISH` в регистъра), гуми и бронзови дискове, и
  донорски контекст (стъкло, дъги, седалки, тъмно поле на deck-а, светещ DRL и стоп) само за кадъра;
  винаги връща сцената (try/finally). `review_sheets.py` слага рендера и модела един до друг.
  `check_floating.py` мери колко всеки елемент от етап 03 стърчи над кожата ПРЕДИ отворите (stage03
  пази скрито копие `_STAGE03_UNCUT`). `panel_review.py` пише `docs/19-panel-by-panel.md`.
  **Стърчащи 10 → 0:** корпусите на фаровете стърчаха 39 mm над капака в задния външен ъгъл („ушите"
  в предния изглед), задните корпуси 32 mm от стеснената опашка, острието и каналът на входа влизаха
  в задната арка, ламелите 6 mm над капака. Корпусите и каналът вече се режат по вътрешната страна на
  кожата минус 3 mm (`inset_skin`, затворени операнди), острието стои 12 mm над арката, ламелите
  взимат най-ниската кожа по цялата ламела.
  **Дифузьор:** тунел между два крака (docs/14 H), P22 от 2870 (иначе таванът на тунела оставаше
  отделно парче на P39/P40).
  **Финиш:** нова колона FINISH — боя / карбон (праг, ъгъл на прага, сплитер, дифузьор, перки, острие
  на входа) / гланцово черно (ламели, маска, капак на двигателя) / скрити (корпуси, канали). Покрай
  това: CSV на регистъра беше с една стойност по-малко от колоните от самото начало (MOUNT_COUNT
  четеше NEEDS_BUILD_VOLUME) — поправено.
  **Моя грешка в процеса, хваната от `print_qc`:** първият рендер с финиши падна по средата и остави
  скрита видимост за рендер; производството копира частите от етап 03 с нея и STL експортът записа
  девет празни файла, докладвайки успех. Поправено от две страни: рендерът винаги връща сцената,
  копието в производството е винаги видимо, и производството вика ERROR при 84-байтов файл.
  **Файлове:** самотни иглени плочки (0.6–2 mm, закачени по ръб) в P21 и P22 се махат при експорт
  под 25 mm². Измерено след промяната: **41 от 41 файла затворени, манифолд, с положителен обем**;
  26 за лепене + 15 shape-only, всички едно парче, всички в референтния плот; сглобка 4376 × **1850.0**
  × 1002.6, 99.8% в 8 mm, покритие 85.7%. `check_goal`: nothing regressed. Файл `STATEV_001_v055.blend`
  (1.3 MB след прочистване на 44 736 сирачета, беше 3.3 MB), откат v054.
  **Какво ревюто казва честно:** обемите и позициите съвпадат; разликата с рендера е в езика на
  повърхностите (фасетите на маската, вдлъбнатата врата, големия scoop, по-тънкия хълбок) — едно е
  скулптиране, друго е донорът (docs/14 I, отворът на входа), трето е скан S2. Таблицата в docs/19
  казва за всяка част кое е кое.

- 2026-09-30 (4) — **сглобката е точно 1850.0; последният файл с дефект е чист.** P11/P12 (shape-only,
  стените на устата на intake-а) излизаха на 927.8: `solidify` отмества всеки връх по собствената му
  нормала, а на устната, където таванът на джоба среща кожата под прав ъгъл, нормалата е средна и
  връхът тръгва наполовина навън — 11 върха на Z 700. Заключената полуширина вече е стена в
  `thicken()`: върх извън ±925 се връща на равнината (до 2.8 mm, брои се и се печата). P21: една
  игла — два върха на 0.0004 mm един от друг и триъгълник ~0.001 mm² на ръба на undercut-а — четеше
  като 2 отворени + 1 non-manifold. Първият ми лек — `tidy_for_export` да хвърля триъгълници под
  0.01 mm² — **отвори девет файла** (P01 сам 230 отворени ръба): толкова малките триъгълници са
  истински свръзки по фугите на булевите. Върнато; остава само слепване на върхове под 0.001 mm,
  което иглата не хваща (върховете ѝ са на 0.5 mm, не на 0.0004 — бях прочел числото грешно).
  **Комитът f34b7a1 твърди „41 от 41 чисти" и това е невярно** — беше написано от предишния лог,
  преди `print_qc` да е пуснат след промяната. Истината: **41 файла, 40 чисти, P21 с 2/1 ръба**
  както преди; сглобка 4376 × **1850.0** × 1002.6, 99.9% в 8 mm, покритие 85.2%.

- 2026-09-30 (3) — **ref-09 отстрани НЕ е калибрируема цел; „гърбицата" на хълбока е в 23 mm от
  ref-05.** Проверих дали двата рендера се разминават по горната линия отзад. ref-09 калибриран по
  междуосието (5.19 mm/px): дължина на колата **3948 mm** при заключени 4370 (нос −840, опашка 3108),
  а по диаметъра на гумата мащабът излиза 5.6 mm/px — 8% разлика, тоест колелата в рендера са по-
  големи спрямо междуосието, точно както `CLAUDE.md` предупреждава за рендерите. Вертикалата няма
  защитим мащаб: по междуосието нашият deck е ~100 mm НАД ref-09 (2400: 1024 срещу 936), по
  височината на cowl-а (донорски 970 срещу ~781 в рендера) е ~100 mm ПОД. Вярната формулировка:
  ref-09 дава ФОРМА (план, изгледи, нормализирани), ref-05 дава милиметри отстрани, и по ref-05
  задницата е на 23 mm. Гърбицата не е грешка спрямо авторитета; ако собственикът иска правата
  падаща линия на ref-09 отзад, това е смяна на авторитета за силуета (ref-05 → ref-09), тоест
  дизайнерско решение с цена в deck-а (BLOCKED до скан S2).

- 2026-09-30 (2) — **v054: три опита върху „мекото" тяло, всеки премерен; двата опровергани.**
  (1) **Рампа за стената/платото на калника** — точките се включваха с твърд праг при −600 и
  изглаждането по X го размазваше в буца над фара (z(x) при Y 800 стъпваше 27/36/30 mm на 25 mm
  срещу 14–19 отстрани). Сега офсетите растат по smoothstep над −700..−450. Измерено след: най-
  лошата стъпка 36 → 31, вълната остава (16,17 → 26,30,31): не беше единствената причина. Оставено,
  защото е непрекъснато по построение. (2) **Фасети между котвите** (`facet()`, α по зона) —
  параметричният аналог на етап 02: хорда между съседните характерни линии. Три пуска на една база:
  само котви → видими равнини на капака и вратата, но гребенът на buttress-а не е котва и хордата
  мина под него — заден силует 23 → 56 mm; плюс всички локални екстремуми → рендерът идентичен на
  loft-а, `surf_x` до третия знак; само екстремуми с 6 mm prominence → същото. **Извод, който
  струва повече от промяната:** между линиите си профилът вече е почти прав — полетата от две
  седмици са го направили такъв. Това, което чете като купол в гланца, е **надлъжната форма**: buttress-
  ът като гаусиан по X, таблиците на гребена, планът — записани дизайнерски решения, не конструкция.
  `FACET_AMOUNT` на нула, кодът стои. (3) PCHIP от v052 — също без визуален ефект, потвърдено.
  Числа: 41 файла, 40 чисти, 26 + 15 секции едно парче, одит 22/3/13/4, покритие 85.2%, endview
  задница 0.08 → 0.06, нищо не регресира. Файл `STATEV_001_v054.blend`, откат v053.
  **Какво следва от това:** loft-ът НЕ е ограничението на сечението — то е ограничение на надлъжните
  линии, тоест на числата в таблиците, които са прочит на ref-05/ref-09 през донора. Промяна там е
  дизайн, не поправка, и се прави линия по линия срещу рендера с рендер-сравнение, не с метрика.

- 2026-09-30 — **v053: втори проход по „летящите" елементи.** Собственикът: „все още има летящи
  елементи". В чистия рендер летяха: рамките на фаровете (P29/P30 — 18 mm рамка в прореза с въздух
  отвсякъде), и отзад три вложени правоъгълника — централна маска (P34), рамка на номера (P36) и
  обрамчението на ауспуха (P35), всяко увиснало в собствения си джоб. В ref-09 задната плоскост под
  стопа е гладка и има **точно два кръгли накрайника** в центъра на дифузьора (заключено в docs/14).
  Направено: **P29/P30/P34/P35/P36 оттеглени** (кодът зад `PARASITIC`); прорезът на фара остава като
  отвор, корпусът P24/P25 се вижда в него; номерът пази **плитко гнездо 30 mm** без рамка (законово
  трябва да седи някъде); ауспухът е **два кръгли отвора Ø104** по обвивката EXHAUST (3220, Y ±65,
  Z 430), накрайниците са купешки. Регистър 47 → **42**. Чистият режим на рендера показва само тялото
  с отворите + острие във входа, ламели, рамка на устата, перки.
  Числа: 41 файла, 40 чисти (P21 2/1 ръба, стар), 26 + 15 секции едно парче, одит 22/3/13/4,
  покритие 85.2%, за котиране 22 части / 6.98 m² / ~26 kg, нищо не регресира.
  Файл `STATEV_001_v053.blend`, откат v052. Оттук: етап 02.

- 2026-09-29 (12) — **v052: всички таблици и сеченията C1 по X (PCHIP); буците не са от възлите.**
  Хипотеза от чистия рендер: вълни 300–500 mm = стъпката на възлите, защото всяка надлъжна таблица
  (гребен, belt, рамо, flank top, spine-ове, центрове на каналите) и преходът между master сеченията
  бяха линейни — чупка на всеки възел. Заменени с монотонна кубична интерполация на Fritsch–Carlson
  (`_pchip`: C1, без overshoot, плоска в локален екстремум, две точки = стара права); сеченията се
  интерполират през ВСИЧКИ сечения, които носят дадено ниво, не само през двете съседни.
  **Резултат, честно:** метриките се подобряват или стоят (предница 4 → 3 mm, задница 23 → 22,
  кривина 0.33 → 0.31, `surf_z` 7.57 → 7.38, план 3.9 → 4.1 в допуск), но **визуално буците остават**
  — те са от самата конструкция на полетата (гребен/стена/плато/долина на всяка станция), не от
  интерполацията. Промяната се пази, защото C1 е правилно и нищо не регресира; хипотезата е
  опровергана като обяснение на картината. Покрай това PCHIP премести пода на задния ъглов джоб
  на 4 mm от ръба на undercut-а и P21 излезе на три парчета (две лица 10 × 12 mm) — джобът вдигнат
  на Z 352, P21 отново едно парче. 46 файла, 30 + 15 чисти + P21 с 2/1 ръба, 31 + 15 секции едно
  парче, одит 27/3/13/4, покритие 85.5%. Файл `STATEV_001_v052.blend`, откат v051.
  **Извод за следващата стъпка:** loft през сечения + полета е стигнал тавана си и по трите
  измервания, и по картината. Пътят напред е етап 02 — повърхност от петна между характерните линии
  (docs/16, карта 5×G0 / 10×G1 / 2×G2), зона по зона, страната първа; или ръка върху повърхността.

- 2026-09-29 (11) — **v051: „паразитните" елементи махнати; чист режим на рендера; гуми.** Ревю на
  собственика: „никак не ми харесва как изглежда, има доста паразитни елементи". Проверено срещу
  ref-09 елемент по елемент: прътовете в ъгловите входове (P48/P49), лайстните (P50/P51) и задните
  ъглови перки (P52/P53) са отделни тела, залепени на кожата, а в рендера съответните неща са ръбове
  и гънки на самата повърхност. **Оттеглени** (кодът стои зад `PARASITIC = False`, номерата не се
  преизползват). Регистър 53 → **47**. Оставащите елементи са функционални или в рендера: острие във
  входа, ламели, рамка на устата, задна маска / номер / ауспух, перки, рамки на фаровете, корпуси.
  **Гуми:** сивите 48-стенни цилиндри правеха всяка снимка на играчка — рендерът строи 19" гуми със
  заоблени рамене и бронзови дискове по донорската следа, само за кадъра.
  **Чист режим** (`GLOSSY_SOURCE = "clean"`): тялото с всички отвори под Catmull-Clark ×2 с crease по
  истинските ръбове, плюс само видимите елементи — без корпуси, канали, платна, застъпвания и езичета.
  Той показа това, което частите криеха: **самото тяло е меко и на буци** — вълни по капака и
  хълбока с дължина 300–500 mm, тоест стъпката на възлите в таблиците (линейна интерполация е чупка
  на всеки възел), и купол на хълбока. Следващата стъпка е там, не в нови елементи.
  Числа: 48 файла, 0 с дефекти, 31 + 17 секции едно парче, одит **27/3/13/4** (по-малко части;
  първоначално бях записал 29/3/11/4, без да съм го чел — поправено от committed-нария CSV),
  покритие 85.9%, нищо не регресира. Файл `STATEV_001_v051.blend`, откат v050.

- 2026-09-29 (10) — **v050: капакът като купол вместо ръб, наклонен преден ръб на scoop-а, и два
  тихи провала на boolean-а, хванати от заключената ширина.** Гланцът показа ръб по средата на капака:
  сечението свършваше с една точка на осевата линия и от долината (или гребена) повърхността вървеше
  права нагоре до нея — 20° чупка в огледалната равнина при specX −500 (90 mm за 500 mm). ref-09 има
  широк мек купол между двата гребена. Две рамени точки (0.5·y при crown − 0.3Δ, 0.2·y при crown −
  0.05Δ) свалят чупката на 4–5°; короната (`HOOD_SPINE`, силуетът) не мърда; само пред cowl-а.
  **Цена, записана:** кривина 0.30 → 0.33 (преден калник 0.38 → 0.45, нос 0.23 → 0.26) — куполът е
  двойно извит по определение, а ръбът беше „цилиндричен"; `surf_x` 3.85 непроменено, силует и
  изгледи непроменени. Базата презаписана с тази причина.
  **Scoop:** устата на intake-а не може напред — донорският отвор е 1900..2080 (`side_intake_x` в
  клетката), а пред него OEM панелът е плътен под 30 mm overlay; scoop-ът на рендера почва на вратата,
  защото кабината му е ~240 mm по-напред от 986 (docs/14 I). Направено е каквото може: предният ръб
  се накланя назад отгоре като в рендера — долният преден ъгъл на 1925, горният на 2000 (Z 455..500 →
  447..700). `X_INTAKE` от 1910.
  **Boolean:** първият пуск даде **ширина 1998.9 при заключени 1850** — cutter-ът на устата беше
  оставил външното си лице (Y 999) в тялото, и „2 върха в задната арка" в `check_donor_fit` бяха
  същите върхове. Хипотеза 1 (усукани четириъгълници → триангулация) **опровергана в изолация**:
  триангулираната призма ПРОВАЛЯ рязането на задния обем (999), обикновената реже чисто (925).
  Причината: cutter-ът застъпва граничната равнина страна/задница (1933) с 8 mm и точният solver
  върху такъв резен е неопределен — в изолация връща обекта непроменен, в пълния строеж залепва
  cutter-а. **`cut()` вече пропуска застъпване под 10 mm по X и го казва** (`SLIVER_MM`). Триангулацията
  е върната, бележката стои в `prism()`.
  Резултат: заключените 4370 / 1850 проверени; **54 файла, 0 с дефекти**, 37 + 17 секции едно парче,
  одит 33 / 3 / 13 / 4, покритие 85.9%, донор CHECK 1 (само носът). Сглобените файлове четат ширина
  1854.3 — `P11/P12 SIDE_INTAKE` (shape-only, SCAN REQUIRED) излизат на 927.2 във второто си парче,
  2.2 mm на страна; не е гонено днес, записано. Файл `STATEV_001_v050.blend`, откат v049.

- 2026-09-29 (9) — **v049: задницата като кутия, ъглови остриета отзад, и лъскавият рендер като
  инструмент.** Тръгна от думите на собственика „панелите не изглеждат готови спрямо формите от
  рендера" при метрики, които всичките минават. Първо направих това, което никога не бях правил —
  **рендер със същия финиш като ref-09** (`glossy_renders.py`: тъмнозелен металик, студийна светлина).
  Глината с cavity shading крие ръбовете (устна 67°, undercut 70°, гребен 61° не се виждат в сиво) и
  показва бучки; гланцът показа две неща: (1) **формата е мека** — купол отзад, купол на хълбока,
  централен гребен на капака; (2) **отраженията са накъсани на вълни по една станция** по вратата и
  хълбока. За (2) хипотезата ми беше разбъркването на семплите между станции (бележката от 21 септ.);
  **опровергана с число**: с едно фиксирано разпределение за цялата кола `surf_x` чете същите
  3.968 mm до третия знак, а вълните изчезват при Catmull-Clark ×2 на същия меш — те са шейдинг на
  60-точков quad-меш на 40 mm, който печатните файлове никога не носят (`smooth_for_print`).
  Поправката е върната; бележката стои до loft-а. Оттук нататък гланцът се съди по **файловете**
  (`GLOSSY_SOURCE = "files"`, `rv_glossy_files_*.png`), не по тялото.
  За (1) — най-видимото, което не е зад скана: **опашката като кутия** (S13/S13b: стена Z 330..600,
  ъгъл на 640..680, deck непокътнат), прочетена от задния изглед на ref-09 при 1.705 mm/px (плоска
  вертикална плоскост до полуширина ~810, ъглови остриета 810..925); **ъглови джобове отзад**
  (Y 690..760, Z 340..575, под на 3180, отворени и настрани — първият опит до Y 800 нямаше външна
  стена никъде, същата грешка като носа във v047, измерена и стеснена); и **P52/P53 TAIL_CORNER_BLADE**
  — 30 mm перки на Y ±850, 3060..3230, Z 150..600, най-външният елемент на задницата в рендера,
  стоящи във въздуха с джоба между тях и плоскостта. Регистър 51 → **53**.
  Метрики: план 4.0 → 3.9%, всичко друго непроменено (силует 4/23/16, изгледи 0.03/0.08, ръбове
  3/2/0, кривина 0.30, `surf_x` 3.97 → 3.85). Опашката „tail" зона 0.13 → 0.11. **52 файла,
  0 с дефекти** — P21 (4 отворени / 2 non-manifold от 21 септември) се оправи от кутията: ръбовете
  идваха от елипсата под стопа. 37 + 15 секции едно парче, одит **33 / 3 / 13 / 4**, покритие
  **86.0%**, за котиране 31 части / 7.22 m² / ~26.8 kg. Файл `STATEV_001_v049.blend`, откат v048.
  Какво остава по форма и не е зад скана: страничният scoop (ref-09: голям, с диагонален преден ръб
  от задния ръб на вратата в хълбока; нашият е плитък правоъгълен джоб) и куполът на хълбока над
  колелото. Зад скана: deck, капак, ламели, платната.

- 2026-09-29 (8) — **v048: носът като кутия с фаска, не елипса; устата беше прочетена наопаки.**
  Три измервания срещу ref-09 преди да се пипа: (1) планът на носа беше **−44 / −37 mm** при 4 / 9%
  от дължината (рендерът: плоско лице 0.549 W на върха, фаска до 0.830 W за 175 mm ≈ 56°, после
  0.922 W при 9%; нашият: 500 → 700 за първите 100 mm и заоблен нататък); (2) предният изглед,
  увеличен 3×: устата е **по-широка горе** (полуширина ~380 при Z 430) и по-тясна долу (~320 при
  Z 220) — записът от 26 септ. „357 горе / 467 долу" е същата форма, огледана по височина;
  (3) ъгловите входове са отвори В фасковото лице (полуширина 578..773), а нашите кутии Y 600..820
  излизаха през кожата (600..740) и ъгълът беше изрязан странично, без външна стена.
  Направено: `S00/S01/S01b/S02/S03` — вертикална лента Z 200..500 с една полуширина на станция
  (496 / 655 / 765 / 812 / 850), под почти колкото лицето (сплитерът е плоча, не корем);
  `NOSE_BITES = False` (страничните изрези от v011 са изключени — те правеха ъгъла ниша);
  `FRONT_CREST.y` на върха 240 → 480 / 600, за да е предният ръб ъгълът на плоското лице, не било
  на 240 mm от оста; ъглов джоб `CUT_CORNER` от −1000 до под на −750, Y 585..745, Z 240..480
  (49 mm дълбок отвън, 149 отвътре, 20–35 mm кожа навън); острие P48/P49 от лицето (лъч ОТПРЕД —
  написано отвътре лъчът удряше кабината и острието свършваше на specX +342) до 20 mm в пода;
  `MOUTH` 320/220 → 380/430; лайстните P50/P51 с лъч само отпред (със страничния лъч първата рамка
  падаше на фланка при Y 769). **План 0/4/9%: +6 / +16 / −5 mm; 4.2 → 4.0%.** Силует 4/23/16,
  изгледи 0.03/0.08, ръбове 3/2/0 — непроменени.
  **Кривина 0.27 → 0.30, записано като причина, не като бъг:** A/B срещу v047 по зони — зона „nose"
  0.16 → 0.23 (все още controlled), **всички останали зони идентични до втория знак**; кутия с
  фаска има ъгли, където три равнини се срещат, и те са сферични по определение. `surf_x` 4.44 → 3.97
  потвърждава, че повърхността е мръднала. Базата презаписана.
  Верига: 47 части, одит **31 / 3 / 13 / 4**, 35 + 15 секции, всички едно парче, **50 файла,
  49 чисти** (P01 вече чист; P21 4 отворени / 2 non-manifold). За котиране: 31 части, 7.05 m², ~26 kg.
  **Покритие 86.2 → 84.2% и това е аритметика, не дупка:** носът от корем стана плоска кутия и
  кожата му е с ~0.17 m² по-малко (P01 0.82 → 0.78, джобовете вадят кожа), а непроизведените
  зони (deck, капак) не мърдат — делът пада, нищо не липсва. Проверено лице по лице: непокритото в
  предния обем 4.19 → 3.19 m². Покрай това `assembly_check` семплираше n-gon по първия му триъгълник
  с теглото на цялото лице — поправено (триангулация), 84.7 → 84.2, т.е. старият семплер ласкаеше.
  Нов `review_renders.py`: шест еднакви изгледа при всяко пускане, за да има „преди" за всяка снимка.
  Файл `STATEV_001_v048.blend`, откат v047.

- 2026-09-29 (7) — ревю: вдлъбнатината на устната е свалена на Z 194 (при 200 таванът ѝ съвпадаше с
  пода на устата за |Y| < 450); ивицата 40 × 438 × 3 изчезна, но P01 остава с 8 отворени + 4
  non-manifold ръба — причината е другаде (лайстни/ъгли/DRL канал), не е гонена. 50 файла, 48 чисти.
  Огледала (P37/P38): нито чертежът, нито клетката носят позиция на огледалото — остават без обвивка.

- 2026-09-29 (6) — **v047: лайстните и устната на сплитера — вече с елемент, който следва кожата.**
  `ribbon()`: за всяка станция по пътя лъч намира точката и нормалата на кожата и през тях се
  loft-ва правоъгълник (24 напречно × 10 навън + 14 навътре по нормалата) — `blade()` измества само
  по Y, `slab()` екструдира по Z, и върху нос, който се накланя 30–50 mm между Z 400 и 500, и двете
  стояха ту вкопани, ту във въздуха. **P50/P51** — лайстна от края на фара до Y 500. Не стига до
  ъгъла на устата: лицето при заключения връх (−950) е плоско навътре от Y ~450 и ръб 12 mm навън там
  даде **4382 при заключени 4370** — измерено от собствената проверка на stage03, върнато; нищо не
  стои пред върха. **Устната:** дължината е заключена, нищо не може да излезе пред върха, затова
  лицето е ВДЛЪБНАТО 40 mm над устната (Z 150..200, −1000..−910) и устната стърчи 40 mm спрямо
  лицето над нея — същият прочит, вътре в заключената кутия; стените се печатат с P01/P28 (`X_LIP`).
  Подът на вдлъбнатината излизаше като файл 40 × 438 × 3 mm към P28/P41 — правило за „sliver": парче
  с кутия не по-дебела от стената и под 10% от главното се изхвърля и брои. Регистър 51 части,
  **50 файла, всички едно парче, покритие 86.2%**, медиана 0.14, 2 файла с дефекти. Метрики
  непроменени. Височината на сглобката чете 1001.6 — платната P17/P18 (върхове 1120 в файловете,
  стъпили на построения хълбок), не тялото (904).

- 2026-09-29 (5) — **v046: носът, втори pass — по въпроса на собственика „предната броня съвсем не
  прилича на рендъра".** Диагноза с числа на v045: лицето на носа е вертикално на specX −950 от прага
  до Z ~500, **DRL-ът беше на 420, а ръбът към капака — заоблен между 500 и 560**: 80–100 mm сляпа
  стена над светлината и мек rol. Отстрани ref-05 дава върха на носа на 557–560 (съвпадаме до 3 mm),
  отпред ref-09 слага DRL-а на самия преден ръб. Направено: (1) `nose_face()` държи лицето вертикално
  (наклон 0.05) до височината на гребена, който е предният ръб и е котва; (2) `DRL_Z` 500 център →
  560 ъгъл — на ръба; (3) долината между гребените е таблица по X и е нула до −700 (в носа даваше
  80 mm гърбица на 120 mm ширина — „очите" в предния изглед); (4) конструкцията стена/плато на
  калника е изключена пред −600 — слагаше стъпала в лицето; (5) **фаровете на ъгъла** под края на
  DRL-а (PROJECTOR −600 / Y 645 / Z 560, измерено: връх на тялото 640–684 над кутията, страна ~800):
  прорез от ъгловото лице до корпуса, рамка 18 mm на −760..−732 (на −790 стърчеше 16 mm пред кожата
  при Y 700 — измерено и върнато), DRL пътят свършва в прореза (−762, 680); (6) **ъгловите входове
  като кутии** (−900..−700, Y 600..820, Z 200..470) с вертикално острие 20 mm → **P48/P49** (острието
  на Y 705 стоеше във въздуха пред лице на −676 — преместено на Y 660, вкопано 40 mm в пода).
  Метрики: всички непроменени (силует 4/23/16, план 4.2, изгледи 0.03/0.08, ръбове 3/2/0).
  Регистър 49 части; 48 файла, покритие 85.5% (кутиите махат кожа), медиана 0.13.
  **Не е направено и защо:** диагоналните лайстни между устата и ъглите — опитът да се сложат като
  slab по лицето засяда в това, че лицето се накланя 30–50 mm между Z 400 и 500 при Y 500–600, тоест
  плоча с постоянен Z стои ту вкопана, ту във въздуха; иска повърхностно следване, което `blade()`
  няма. И **мекотата на самото лице** остава: loft през сечения дава заоблен преход там, където
  рендърът има равнини — това е разликата между параметър и скулптура, `docs/16` го казва от 15 септ.

- 2026-09-29 (4) — **Счетоводство по обвивките:** `HOOD_VENT` (DECIDED от 14 септ., никога не
  построен) е SUPERSEDED — отдушниците на ref-09 са прорезът в калника P05/P06 с четирите ламели;
  `DOOR_VENT` е DEFERRED — прорез в OEM кожата на вратата не може да вентилира арката, а прорез в
  задния ръб на калника иска канал през вътрешния калник, който само сканът поставя; не е строен и
  не е фалшифициран. P23 REAR_SPOILER стои в регистъра с въпрос към собственика (ducktail-ът е в
  профила на опашката от v031; обвивката е 125.7 mm вътре в тялото): да се погълне в P21/P19 или
  да остане отделна устна. Без промяна по геометрия.

- 2026-09-29 (3) — **v045: buttress остриетата съществуват като shape-only, извън предполагаемия
  обем на покрива.** `docs/14` блокира deck-а (височината му е в обема на сгъване, известен само от
  скан S2). Не е блокирано острие, което стои НАВЪН от този обем: `ROOF_FOLD_ENVELOPE` (PROVISIONAL,
  предположение) свършва на Y 650; остриетата са 40 mm платна на Y 685..725 върху горнището на
  хълбока, specX 1800..2750, върхове 1120 зад ролбарите → 990 при опашката (ref-09 отзад: високи,
  тънки, точно под върховете на ролбарите). Стъпват 14 mm в построената повърхност. **P17/P18 в
  shape-only реда с най-силната бележка:** самият обем е предположение; стъпалото, deck-ът между тях
  и дали изобщо могат да съществуват чакат S2 — печатат се, за да се гледа задницата, не за лепене.
  `assembly_check` не брои региона им като „с файлове" — иначе 100–200 mm празнина на deck-а влизаше
  в статистиката на веригата (99-и персентил 1.98 → 100 mm). **48 файла, покритие 86.6%**, медиана
  0.15, 99.9% в 8 mm, 1 файл с дефекти. Масата на stage-03 тела е при 100% запълване (платно 8 kg
  при 40 mm плътно) — печатат се с infill, числото е горна граница. Кадри: `review/rv_rear34.png`.
  Първите два опита сложиха остриетата в READY TO BOND (бяха в PANELS) — поправено: shape-only
  stage-03 част стои в SHAPE_ONLY и STAGE03, не в PANELS.

- 2026-09-29 (2) — **Цели панели, но не по-големи от плота: 46 файла, всичките се побират, всичките
  едно парче.** Досега калниците (833 високи при 600 дълбочина) и праговете (1827) стояха с
  FITS_BED=NO. Сега част, която не се побира в референтния плот в никаква ориентация, се реже на
  най-малкия брой равни парчета с езичето от секционния период, и **оста се избира**: по X калникът
  не ставаше по-нисък от 833, докато резените не станат под 580 — три среза, седем парчета, щом
  арката раздели всеки резен. Един срез по Y го прави: калник 3 файла (горна лента + външна част,
  която арката дели на две), хълбок 2, праг 2. Без член за стената в теста — тя върви навътре и не
  расте кутията; с него хълбокът (581 при 580) се режеше за 6 mm, които никога не заема.
  Сглобка непроменена: медиана 0.15, 99.9% в 8 mm, 85.9%. Метрики непроменени.

- 2026-09-29 — **v044: отпечатаните панели са гладки там, където дизайнът е гладък.** Измерено на
  v043: медианният двустенен ъгъл между съседни лица по обшивката над Z 400 е **3.7–5.9°** при
  рингове през ~38 mm — ядро, печатано от това, носи видима фасета на всеки 38 mm (1–4 mm сагита по
  тесните радиуси) и ламинатът я следва. Резолюцията на loft-а е измерителен избор (всяка метрика
  се чете от този меш) и остава; ПЕЧАТЪТ се подразделя — `smooth_for_print()`: Catmull-Clark 2 нива
  върху повърхността на панела преди стената, ръбове над 25° (устна, гребен, рафт, всяка стена на
  джоб) са creased, контурът се пази (PRESERVE_CORNERS), за да се срещат фугите. P09: 557 → 8880
  лица, медиана 2.3° → 0.5°, отклонение от master-а медиана 0.13 mm, 90-и 0.94, макс 5.5 (в ъгли).
  Сглобка: медиана 0.15 mm, 99.9% в 8 mm; файлове общо 33 MB.
  **Масата на ядрото 47.9 → 62.6 kg е поправка, не растеж:** грубият solidify губеше 12–15% обем в
  прищипани ъгли (P01 2903 срещу очаквани 3423 cm³ за 11411 cm² × 3 mm; подразделен 3385).
  DRL каналът стана полукръг r 7 с ос НА кожата — с ос 4 mm навътре беше по-широк отвътре,
  отколкото на устата (undercut), лицата на устните гледаха назад и стената им излизаше навън.
  Файлове с дефекти **2 → 1** (P21: 4 отворени + 2 non-manifold). Дължината на сглобката 4376 при
  4370 (по 3 mm на върха на всяка фасада) стои отпреди сегментния период — 14 лица на горното
  острие на носа с нормала назад-нагоре; не е гонено повече, вътре е в припуска на ламината.
  Метрики непроменени (тяло → метрики → stage03).

- 2026-09-28 (6) — **Тестът за ръбове вече вижда рафта на прага: 0.9° → 65.5°.** Двете чупки на
  рафта (65.7 и 65.0°, премерени на ръка при specX 1000) бяха там; филтърът срещу стените на арките
  ги хвърляше, защото лицето на рафта гледа нагоре и навън (нормала (0, 0.41, 0.91), радиално 0.17)
  и с вертикалното лице на вратата не минаваше нито „и двете нагоре", нито радиалния тест. Сега
  тестът е по лице: лице, което гледа НАГОРЕ, е кожа, каквото и да е радиалното му — стена на срез
  никога не гледа нагоре (гледа по среза или в нишата). Линията се мери на долната чупка на рафта.
  `docs/16` я води G1, построеното е G0 рафт — това е преправената страна от `docs/14` I, записано в
  изключението, не дефект. Изключение за „shelf-aware finder" вече няма нужда.

- 2026-09-28 (5) — **P11/P12 SIDE_INTAKE в shape-only реда; покритие 84.9 → 85.9%.** Одитът ги
  води „donor-governed SHAPE: истинският отвор зад тях управлява устата" — същият клас като хълбока
  P15, който е shape-only от 21 септ. Външната форма е наша (обрамчението на входа, specX 1780..2300
  над прага), отворът и каналът зад него са на донора и идват от скана. 520 × 497 × 375 mm, по едно
  парче. 38 файла, медиана 0.00, 99.9% в 8 mm. Остават без файл: buttress-и, deck, капак на
  двигателя (roof fold), ламели, спойлер, огледала (без обвивка).

- 2026-09-28 (4) — **v043: DRL-ът е канал във фасадата, не крива в колекция.** Острието на DRL-а
  стоеше като крива в `04_LIGHTING` от 14 септ. и нищо не беше рязано за него — най-силният подпис
  на предницата в ref-09 съществуваше само като обвивка. Височината му се решаваше от СЕЧЕНИЯТА
  (данни отпреди loft-а) и даваше 350 в центъра (ВЪТРЕ в устата 200..385), 450 по средата и
  400 / 552 / 443 към ъгъла — зигзаг. Сега е таблица по |Y| (`DRL_Z`: 420 център → 490 ъгъл, плитко V
  над устата, под прореза на фара 505..625; позиционните светлини искат ≥ 350). Hella LEDayFlex се
  монтира в канал, така че корпусът Е канал: тръба r 8 по `DRL_PATH` с ос 4 mm под кожата (лъч към
  повърхността от три посоки, най-близкият удар), изрязана от фасадата — стените ѝ се печатат с P01.
  **Поука по мярката:** първият пуск даде кривина 0.29 (REGRESSED) при непроменени `surf_x/z` —
  бях мерил СЛЕД stage03, а базата е измерена преди него; тръбата на канала е сферични върхове.
  Ред на измерване: тяло → метрики → stage03. Премерено вярно: 0.27, нищо не регресира.
  Донор +61 / +22 / +28, 36 файла, 84.9% покритие, 3 с дефекти (P01 3, P21 13, P22 1 ръба).

- 2026-09-28 (3) — **v042: страната е непрекъсната през двете shut-линии, прагът е едно острие от
  арка до арка, донорът е чист и на трите ленти.** Измерено на v041: при 440 вратата беше по средата
  на рампата си (880 при specX 440 срещу 912 при 500 на Z 600 — 30–80 mm промяна в 60 mm зад задния
  ръб на калника = стъпало между калник и врата), а при задната shut-линия острието свършваше и прагът
  падаше 918 → 874 (Z 250, 1620 → 1680). Калникът е подменяна част без донор зад него — носи същото
  сечение в последните 100 mm; хълбокът — 85 mm; `DOOR_OUT` 340..1720, `ROCKER_BLADE` 340..2040.
  Клампът за вратата тръгва от 360, за да е пълен на 440 — на самата shut-линия подът на канала
  беше 797, 47 mm вътре в OEM вратата, защото w = 0 там. Проверено: 918 от двете страни на двете
  линии на Z 250/600/700; **праг +61, врата +22, хълбок +28** — първи път трите OK без изключение.
  Метрики непроменени (план 4.3 при база 4.2, в допуск). 36 файла, 84.7%, 2 с дефекти (P21, P22).

- 2026-09-28 (2) — **Файловете за печат: 6 → 2 с дефекти, и причината не беше прищипване.**
  Проследено на P21: мешът в Blender няма дублирано лице и има само 3 ръба, които се сливат по
  позиция в повече от две лица (шевът y = 0 на стените на джобовете), а `.stl`-ът има 34 — и 31 от
  тях носят **два съвпадащи триъгълника**. Мешът има ngon-и до 48 върха (подове на джобове от
  boolean, ръбът на стената), някои се допират до себе си във връх, и тесселацията на експортера
  слага два еднакви триъгълника върху такъв ngon. Сега `tidy_for_export()` триангулира сам (beauty)
  и маха изродените и дублираните по позиция триъгълници. Резултат: **2 от 36 файла** с нещо за
  казване (P21: 8 отворени + 4 non-manifold ръба — там, където дубликатите са били от две различни
  съвпадащи повърхности; P22: 1). Точността и покритието непроменени. Опитът да се откачат и
  малките ветрила при прищипване в whole режим не промени нищо — прищипванията не бяха причината.

- 2026-09-28 — **v041: страната е преправена НАВЪН от донора — два насложени канала, и планът
  съзнателно се отклонява от ref-09 при вратите.** Решението е по правилото на CLAUDE.md за
  принудена инженерна промяна (най-малката промяна по засегнатата повърхност, записана) и hard
  constraint 3; собственикът може да го отмени (`docs/14` I). Какво е построено:
  клампът към донора е ВКЛЮЧЕН (`DONOR_CLAMP`: праг 250..2200 / Z 125..330, врата+хълбок
  440..2500 / Z 330..800, `DONOR_CLEAR` 30 — 20 се губеше от изглаждането по X, измерено 8–11 mm);
  горната част на вратата е избутана до **918** (`DOOR_OUT`, Z 570..760, fade 14), така че каналът
  е издълбан в ДОБАВЕНАТА дебелина с под на donor+30 (~875) — **~45 mm канал с истинска устна:
  68.9° при дизайн 72.4**; прагът стои като **острие на 918** (`ROCKER_BLADE`, Z 125..330) и в него
  stage03 реже DECIDED `ROCKER_CHANNEL` (Z 195..285, 68 дълбок, под ~850 над OEM праг ~818).
  Донор: **праг +32, врата +15, хълбок +29** (беше −188 / −125 / −162).
  Цената, измерена: **план 2.4 → 4.2%** — +100 mm при 43–57% от дължината, точно вратите, където
  ref-09 има талия 0.88 W (814), а OEM вратата е на 845–860. Записано като причина и базата е
  презаписана. Другите: силует 4/23/16, изгледи 0.03/0.08, кривина 0.27, surf_z 9.23 → 7.55 (по-добре).
  Ръбове: **3 в лента / 2 изключения / 0 дефекта** — „долното рамо на канала" и „главната странична
  линия" са SUPERSEDED (лежат вътре в избутаната врата, няма ръб по дизайн); линията на прага е
  вече рафт с две G0 чупки на 30 mm, а тестът я чете <1°, защото хваща ръба на плоското над рафта —
  записано като изключение с причина, не като минаване. Две грешки по пътя, и двете измерени:
  клампът до 2600 стигаше през изглаждането до ръба на undercut-а (69.8 → 40.9°) — зоната на
  прага свършва на 2200; котвата на острието на 250 зад него сядаше върху котвата на undercut-а —
  A/B с единствена разлика 250/200 даде 44.1 срещу 69.4°. Панели: **36 файла, 84.7% покритие**,
  медиана 0.00 mm, 99.8% в 8 mm; 6 non-manifold (P01 13 и още пет с по 1–5 ръба).
  Кадри: `review/rv_side34_low.png`, `review/rv_panels_front34.png`.

- 2026-09-26 (15) — **Страната е ВЪТРЕ в донора, и това не е било мерено никога.** Лъчи срещу
  `BLOCK_986_approx` по цялата страна: **прагът (Z 150–320) е вътре в OEM прага на 146 от 150
  проби, най-зле −189 mm** (specX 1200 / Z 150: наше 627, донор 817); **вратата (Z 400–700) — на
  101 от 140, най-зле −125** — подът на страничния канал е 126 mm вътре в OEM кожата на вратата.
  Долното тяло е чертано като корпус, който се стеснява към пода, а 986 носи широки прагове; каналът
  е рязан, без нищо да го спре в донора. `check_donor_fit` гледаше носа, арките и хълбока, не прага и
  вратата — сега има три реда за тях (`data/donor_side_986.json`, таблица от блока, ±30–50; стените
  на арките и джобовете се прескачат, защото първият пуск докладва −303 от връх НА цилиндъра).
  Опитан е клампът (`donor_clamp`: сечението не може вътре в донора + 30): прагът стана +15,
  вратата +22, но **страничният канал изчезна** (устната 68° → 3.8°, „светлината не се чупи"),
  страната стана плоча, планът срещу ref-09 регресира 2.4 → 3.2%. Причината е факт за двете
  референции: **талията на ref-09 при вратите е 0.88 W = 814 mm, а OEM кожата на вратата на 986 е
  на 845–860**. Талията от рендера не може да се построи на този донор; негативните пространства
  могат — само НАВЪН от OEM кожата (горна част на вратата до ~918, под на канала donor+30, праг като
  острие на ~918 с DECIDED undercut `ROCKER_CHANNEL`, под ~850 над праг ~818). Това е преработена
  страна и план, който съзнателно се отклонява от референцията — **решение на собственика**, не мое.
  Клампът е изключен (`DONOR_CLAMP = []`, зоните са записани до него), геометрията е v040, конфликтът
  стои като три CHECK реда: **праг −188, врата −129, хълбок −162** (последният при 1760/640 е ръб на
  кабинния срез — да се прескочи в следващия pass). Метрики непроменени, 36 файла, 99.8% в 8 mm.

- 2026-09-26 (14) — **v040: вентилът в калника стана ламелна решетка, и една тиха грешка в
  `surface_z`.** Отдушниците на капака в ref-09 (измерено от горния изглед при 6.5 mm/px: y 380..608,
  specX −400..+40, четири диагонални ламели) са същият отвор като нашия прорез в калника (y 385..545,
  −235..165), в който стоеше една лайсна от 17 септ. Лайсната е заменена с **гребен: четири
  диагонални ламели 6 mm на ~60° към оста върху две релси по стените на прореза**, върхове 12 mm под
  кожата — една част на страна (union на затворени тела), P05/P06, 380 × 154 × 110 mm, манифолд.
  **Грешката:** първият гребен излезе 681 mm висок, до Z 108. `surface_z` търсеше върхове в 26 mm
  и там, където ринговете са редки, не намираше нищо горе и падаше на върховете на ПОДА (120) —
  без да каже. Пуснат беше и върху тяло, което предишен pass на `stage03` вече беше изрязал, така че
  „горе" при y 465 беше подът на прореза. Две поправки: `surface_z` е лъч отгоре, и веригата е в
  реда тяло → stage03 → панели (stage03 върху изрязано тяло реже два пъти). Проверка на Z 120..1025
  в самия `stage03` го хвана — заключените стойности са ограда, не декорация.
  Метрики: непроменени. 36 файла, медиана 0.00, 99.8% в 8 mm, 4 non-manifold.

- 2026-09-26 (13) — **Капакът P02 влиза в shape-only реда; покритие 76.5 → 83.7%.** Стоеше
  „PROCEED на артефакт" и извън всяко производство: построената повърхност свършва на specX ~385,
  където кабинният cutter започва да хапе, 35 mm преди донорския cowl на 420. Този процеп Е
  донорската scuttle-зона — къде реално ляга задният ръб на капака, пантите и отворът на frunk-а
  идват от скана, както линията на вратата при калниците. Припуск не може да се пренесе през
  кабинния срез, затова файлът свършва на 385 и това е записано в реда. **1076 × 760 × 307 mm,
  едно парче**, 36 файла общо, медиана 0.00, 99.8% в 8 mm. Няма промяна по геометрия.

- 2026-09-26 (12) — **v039: дифузьорът съществува; ръбовете на арките спряха да са стълби.**
  Ревю с измерване отдолу: подът на тялото беше **плосък на Z 120 до самата опашка** — панел на
  име дифузьор (P22) и обвивка (Z 130..350) имаше, форма нямаше. ref-09 отзад: под, който се издига
  от оста до опашката, с четири високи перки и корпуса на ауспуха между тях. `DIFFUSER_FLOOR`
  (2870: 120 → 3145: 215 → 3420: 330) вдига пода на сечението в `ring()`, така че loft-ът носи
  равна рампа до ръба на undercut-а (фугата P21/P22 на Z 330). Измерено отдолу: 126 / 155 / 213 /
  289 / 323. Обем 4.239 → 4.186 m³. Силуетът е непокътнат по конструкция — сравнява само горната
  линия; проверено: 4/22/16, план 2.5, кривина 0.24, ръбове 5/2/0.
  **Перки:** четири остриета 16 mm (`stage03`), връх 12 mm в пода, дъно на Z 125 — подът на тялото
  е 120, клирънсът не е пипан. Вътрешни ±150 до 3400, външни ±330 до 3300, защото опашката се
  стеснява до ~260 mm при 3420. **P44–P47**, регистър 43 → 47 части; одит 27 PROCEED.
  **Арките:** правилото за стената на цилиндъра щадеше 12 mm — стената е на 0.6 mm от него, а
  39 (отзад) и 46 (отпред) лица КОЖА по ръба на арката стояха на 1.3–10.8 mm и се хвърляха с нея;
  оттам стълбите по арките на всеки калник и хълбок във файловете. Толеранс 2 mm; ръбовете са
  кръгове (`review/rv_panels_side.png`). Кожа по `panel_extract` 15.53 → 16.31 m² (+0.78, върнатите
  ръбове на арките и подът на дифузьора).
  Файлове: 29 + 6, медиана 0.00 mm, 99.7% в 8 mm, ширина 1850.0; 4 non-manifold (P01 16, P21 32,
  P22 5, P04 1). `supplier_package` вече брои и целия production файл като „файл" — P43..P47 стояха
  на „proven, no file yet" с готови файлове.
  „Опашката завършва остро" — ОТТЕГЛЕНО същия ден, след измерване на горния изглед на ref-09 ред по
  ред: контурът ѝ пада от 0.8 W при 96.4% до центъра при 100%, тоест референцията също се затваря
  в последните ~157 mm, а нашата — в последните 100; планът е в 3% на 96%. Впечатлението е от
  последните 100 mm, не дефект.

- 2026-09-26 (11) — **v038: централната уста съществува за първи път; „устата" дотук бяха два
  ъглови изреза.** `make_cutter` яде НАВЪТРЕ ОТ СТРАНИ, така че `NOSE_MOUTH` от 14 септ. беше
  две огледални захапки 155–215 mm дълбоки до y 357..437 при Z 180–350 — и нито един централен
  отвор, при заключено „голям централен отвор към радиаторите". Прочетено от ref-09 отпред
  (ширина на колата 1010 px): устата е трапец точно под DRL-а, полуширина **357 горе / 467 долу,
  ~190 висока**, сплитер под нея; **ъгловите входове** са на ъгловите повърхности при полуширина
  604..787, ~310 високи; между тях боядисана лайстна ~140 mm. Старите захапки стигаха 150–250 mm
  по-навътре и щяха да се слеят с всяка централна уста.
  Построено като задната маска: `stage03_elements` реже трапецовиден джоб (полуширина 450 при
  Z 200 → 340 при Z 385, под до specX −820) и в него стои рамка 26 mm — **P43 FRONT_MASK**, нова
  част (регистър 42 → 43, FRONT_CLAMSHELL, стъпка 4, +X, direct print). Захапките станаха ъглови
  входове: вътрешен ръб ~590–650, Z 185–480. Крайните станции носят дълбочина 5, не 0 — нулев
  краен пръстен е изродено сечение и exact boolean-ът връщаше ПРАЗНО тяло (10645 → 0 лица);
  тествано изолирано, същата таблица с 5 реже чисто.
  Стените на устата са джоб в картата (`X_MOUTH`): не са кожа, печатат се с фасадата.
  Метрики: силует 4/22/16 и двата изгледа непроменени, **план 2.4 → 2.5%** (в допуск 0.5), кривина
  0.26, ръбове 5/2/0. Stage 03: 16 елемента, 15 отвора, заключените непокътнати. Панели: 25 + 6
  файла, медиана 0.00, 99.8% в 8 mm, ширина 1850.0, 3 файла non-manifold (P01 16, P21 30, P04 1).
  **Какво храни устата е донорски въпрос** — 986 носи радиаторите в ъглите; формата е наша,
  каналът зад пода не е начертан (`what_the_mouth_feeds` в `pilot_panel`).
  Остават по око спрямо ref-09: диагоналните лайстни между устата и ъглите (скулптиране),
  решетката в устата (материал, не форма), и мекият релеф на цялата предница.

- 2026-09-26 (10) — **Производството мина на ЦЕЛИ ПАНЕЛИ — един файл на част, по решение на
  собственика („не много малки, а реално големи цели панели").** Решетката 350 mm от 16 септ. беше
  предположение за плота на печатница и даваше 425 файла, 73 люспи под 40 mm; панел в 20 залепени
  парчета е пъзел, не панел. `panel_production.py`: `split="whole"`; решетката остава като
  `split="grid"` за деня, в който плотът е известен (docs/13 Q26). Референтен плот **1800 × 600 ×
  1800** (Modix BIG-180X клас, който CLAUDE.md сочи като бъдеща собствена машина) — само **флагва**
  кои части не биха се побрали, сортирано срещу сортирано, нищо не се реже по него.
  Резултат: **24 + 6 = 30 файла, 30 части**, точност медиана 0.00 mm, 99.2% в 8 mm, ширина 1850.0.
  Не се побират в референтния плот: праговете (1831 mm) и калниците (829 mm високи при 600 дълбочина).
  Опори при клас-A нагоре: калник 328 L всеки, задна фасада 135 — това е цената на цял панел, легнал
  плоско; Q32/Q33 решава дали се печата изправен. Пет файла с по 1–14 non-manifold ръба (прищипване,
  съзнателното трето правило). `render_panels.py` ги връща на колата в цветове —
  `review/rv_panels_*.png`; две празни картини по пътя: активната колекция и мащабът на импорта,
  и двете записани в скрипта.
  Три неща излязоха само защото панелите станаха цели: (1) **P21 беше 23 файла** — 22 единични
  триъгълника по фугата на undercut-а, 5–4600 mm², които правилото за региона дава на фасадата, а
  всичко, което докосват, е на дифузьора; и **P03 носеше две самотни лица по 2×10⁴ mm²**; сега
  панелът е ЕДНА свързана повърхност — остров под 1/10 от площта се изхвърля и се БРОИ
  (`DROPPED_MM2` в графика, 354 cm² общо, почти всичко P21 по фугата, където P22 носи фланеца).
  (2) Двете самотни лица бяха **крайните стени на прореза в калника** — `not_panel` искаше Y или Z
  нормала и ги пускаше като кожа, а страничните стени режеше; и стените на джобовете **изобщо не
  влизаха във файла** (калникът имаше дупка на мястото на вентила). Сега всяка стена в кутията на
  джоб е не-кожа за счетоводството, но се ПЕЧАТА с панела, в чийто регион е джобът.
  (3) **Таванът на арката минаваше за кожа** — правилото за цилиндъра щадеше почти хоризонталните
  фасети (abs nz < 0.9), а те са фасети от 14 162 mm² с нормала НАДОЛУ, тоест таванът на калника
  отвътре; стигаха до P15 като откъснат рафт 273 × 346. Щади се само каквото гледа нагоре.
  (4) Затворено stage-03 тяло не се удебелява втори път (иначе втора черупка отвътре и два файла).
  Страничен ефект: P02 HOOD в одита от „ours, provable" на „between donor bounds" — той и без това
  не влизаше в производството. Skin по `panel_extract` 16.51 → 15.66 m².

- 2026-09-26 (8) — **v037: формата на рамото отпред и отзад, мерена срещу ref-09 за първи път.**
  Силуетът и планът са контури — нито един не вижда дали калникът е стена с плато или купол.
  `endview_overlay.py` взима горния контур на предния и задния изглед от ref-09 и от маска на
  модела само за зоната (specX < 440 / > 1760), нормализира по ширина и по височината на 25% навътре,
  и сравнява външната четвърт: там е рамото на калника. Референцията и отпред, и отзад е **стена
  (0.36 / 0.55 от изкачването на 1 / 3% навътре), тесен ъгъл, плато (0.63–0.73 между 5 и 11%),
  после горен ръб**. Моделът беше права рампа под ~50°: 0.08 / 0.25 / 0.42.
  **Отпред 0.180 → 0.033** на три стъпки, всяка премерена: гребен и рамо навън (`FRONT_CREST.y`
  600 → 780 при оста; 0.081), после **връх на стената + плато като две котвени точки** (стена до
  `crest − 103` на 6 mm навътре от най-широкото, плато при `crest y + 90, crest − 45`; 0.033).
  Гребенът е 40 mm под короната на капака, а силуетът отстрани го носи `HOOD_SPINE` (старата
  таблица на гребена) — отпред 4 mm непроменено. Долина на y 600, −50, между калник и капак.
  **Отзад 0.189 → 0.078**, с два отхвърлени междинни: върхът на стената вдигнат 660 → 800 с
  34 mm ease даде **рафт** при 17° и **0.305** (нулата на мярката скача на върха на идеално
  вертикалната стена); ease 140 даде 39° фаска и 0.227, защото дърпането пада до нула на върха на
  лентата, а суровото сечение се прибира 84 mm за 65. Верният лост: **`FLANK_TOP_HOLD` 0.45** —
  стената носи част от дърпането до върха и се отпуска 60 mm над него (иначе 74 mm стъпало при
  2800), плюс **`HAUNCH_PLATEAU` на нивото на deck-а** (860/880 при оста при spine 878) — референцията
  държи горнището на хълбока на височината на deck-а, изнесено до стената, а не стъпало по средата.
  Бележката HAUNCH SAIL от 21 септ. четеше референцията като „прибира се над рамото"; измерено, не
  се прибира до платото. Нищо не е свалено: масата е добавена **навън** (y 840–888, Z 860–880),
  извън OEM тялото (890) и извън обема на сгъване. `FLANK_TOP` е таблица и пада към опашката.
  Ръбове: хълбок горе → страна 17.1° при дизайн 15.4 (G1 ok), гребен 62.4 при 64.0 (записано
  изключение), 5 / 2 / 0. Силует 4 / 22 / 16, план 2.4, кривина 0.26 (0.25), surf 4.66 / 9.23 —
  всичко в допуск. `check_goal.py` пази и двете нови числа (**0.03 / 0.08, допуск 0.02**).
  По око (`review/rv_*.png`, гладко шейдване, собствени камери): рамената четат като стена + плато;
  **носът е далеч от ref-09** — устата е един клиновиден срез, референцията има трапецовидна уста
  със сплитер, ъглови входове и DRL острие; шейдването на капака е шумно от триангулацията между
  рингове (позиции: `d²z` < 1 mm на 25 mm извън джобовете); buttress-ите BLOCKED. Привидната
  асиметрия в предния рендър е осветление: тялото е симетрично до 7 mm максимум, 0–1 типично.

- 2026-09-26 (9) — **Две дупки във веригата до файл, намерени от заключената ширина.** Сглобката
  даде 1853.6 при 1850: `P03 s14b` — 12 триъгълника, 15×6×15 mm, откъснат чак СЛЕД удебеляването,
  значи правилото за трохите в `split_pinch` не го е виждало, а `face_outward` без мнозинство го
  удебели навън. `loose_pieces` вече трие парче с кожа под 600 mm² по същото число: **50 такива
  файла по-малко** (241 → 213, 234 → 212), ширина **1850.0**. И втора: изходните директории не се
  чистеха — 578 файла на диска срещу 425 в `placement.json`, и `print_qc` одитираше **153 секции
  от стари номерации** като част от колата. Производството чисти `.stl` преди експорт, `print_qc`
  чете само `placement.json` и докладва сираци. Точност непроменена: медиана 0.00, 99.7% в 8 mm,
  покритие 77.0%, 13 от 425 non-manifold (съзнателният остатък). **Отворено, отпреди:** дължина
  4376 при 4370 — `P01` s06/s08 до 953 и `P21/P22` до −3423, по 3 mm люспа на върха на фасадите,
  същото и на HEAD.

- 2026-09-26 (6) — **`overhang_report.py`: Q32 става брой и литри, а не неизвестна — след три
  бъга в самия доклад, хванати от собствените му числа.** (1) 393 m² „върху опори" при кола с
  12.9 m² обшивка — cm² делено на 100 вместо на 10 000. (2) 49% при 90° на почти всеки файл —
  **долното лице, легнало на плота**, което е основа, не надвес; изключено, и обърнатият вариант
  се пуска отново на плота, преди да се мери. (3) 100% при „worst 62.66°" на P08_s05 — генератор
  вътре в list comprehension, материализиран на следващия ред, когато `t` вече е **последният**
  триъгълник: всеки елемент беше един и същ триъгълник. Генераторът затваря върху променливата,
  не върху стойността ѝ. Направен eager.
  Верният доклад после каза друго важно: ъгълът сам не различава долна страна на 1 mm от плота
  (безплатна) от такава на 100 mm (блок опора). Добавен **обем на опората** = площ × разстояние
  до плота за лицата над 60°. Резултат: производство **222 L**, 99 файла с истинска опора
  (>30 mm), 85 с долна страна, залепена за плота; и **43 файла, които биха искали значително
  по-малко опори обърнати** — `lay_flat` никога не е питал коя страна нагоре.

- 2026-09-26 (7) — **Class-A лицето нагоре, на всяка секция.** `lay_flat` избираше „най-малкото
  измерение вертикално" и оставяше знака на случайността — около половината секции печатаха
  външната кожа надолу, върху опори при извита черупка: най-лошата повърхност, която принтер прави,
  и тази, която после иска най-много кит. Правилото не е „най-малко опори", а **class-A нагоре**,
  защото външното лице се ламинира и финишира, и белег от опора там се плаща два пъти.
  `class_a_normal()` взима претеглената по площ нормала на външната кожа (същият радиален тест като
  `face_outward`), завърта я с ориентацията и обръща секцията за 180° около X, ако сочи надолу.
  Колоната `CLASS_A_UP` в графика: **444 от 444 „yes"**. Цената, измерена: опори 222 → 232 L
  (производство), 214 → 278 L (shape-only) — вдлъбнатата вътрешна страна надолу означава повече
  въздух. Съзнателна размяна, с числа за Q32/Q33. Точност, ширина и осемте метрики непроменени;
  24 доклада current.

- 2026-09-26 (5) — **Припуск за изрязване през донорските линии, за shape-only панелите.**
  `gather` носи материал на съседа през фуга, която е **наша** (фланец, 30 mm, с рампа). Донорска
  shut-линия не е наша, затова през нея нищо не се носеше — и калникът свършваше точно върху линия,
  която чертежът слага с точност ±15–30 mm, без нищо за изрязване до истинската. `trim_at()` добавя
  повърхността на съседа 30 mm отвъд равнината, **без рампа** — припускът е кожа на пълна
  височина, реже се на колата. Равнините са тези на `panel_map.B`, по име, за да не се разминат
  с границите на панелите. Функция, не таблица, защото `panel_map` се зарежда по-долу във файла
  (първият опит падна с `NameError` точно затова).
  Проверено от изнесените файлове: P03/P04 стигат до specX **500** (линия 440), P09/P10 покриват
  **418–1667** отвъд двете линии, P15/P16 тръгват от **1600** (линия 1635); двойките са
  идентични. Следствие, записано в графика: shape-only съседи се **застъпват** с 30 mm при всяка
  донорска линия — нарочно. Цена: люспи под 40 mm 59 → 73, защото ръбовете на припуска добавят
  малки клетки; секции 422 → 444. Точност и ширина непроменени, 23 доклада current.
  Това е последното, което може да се направи по тези шест панела без колата: формата им е наша,
  границата им вече носи запас, вътрешното лице чака скана.

- 2026-09-26 (4) — **Люспите: и двете ми хипотези бяха грешни, и мярката го показа преди кода.**
  Проследено на P21 етап по етап: след рязане **65 секции, 3 под 40 mm, 0 многопарчеви**; след
  стена + разделяне **118 части, 45 под 40 mm**. Люспите се раждат при **удебеляването**, не при
  решетката — записът в `cut_into_sections`, който обвиняваше решетката, е грешен и е поправен.
  Виновникът е моят `split_pinch` от 21 септември: с него P21 дава 118 части / 45 люспи /
  8 non-manifold, без него 65 / 3 / **78**. Той разменяше non-manifold ръбове срещу люспи — откъсваше
  едно-две лица при точка на прищипване, а `solidify` ги правеше призмички с 6–10 върха.
  Две поправки в него, всяка премерена: (1) ветрило под 600 mm² се **изтрива**, не се откъсва —
  резка от няколко милиметра в ръба на черупката, която ламинатът не вижда; P21 118 → 91 части.
  (2) Тестът за прищипване броеше **гранични** ръбове при върха, а „папийонка" с едно изцяло
  вътрешно ветрило има точно 2 и не се хващаше — 21 люспи оцеляха точно там. Тестът вече брои
  ветрилата; non-manifold пада на **0** на P21 и P01.
  Останаха единични квадове от 27–40 mm — над прага за изтриване, под прага за част. Изтрити, те
  оставят 38 mm резка по ръба на панела; откъснати, са люспи. Затова правилото е тристепенно:
  тривиално → изтрива се; малко, но реално → **остава закачено** (един non-manifold ръб, който
  `print_qc` докладва и слайсърът поправя); голямо → откъсва се.
  По целия комплект: **секции 531 → 422, люспи под 40 mm 149 → 59, под 20 mm 68 → 17**;
  non-manifold файлове 11 → 13 (3%), очаквано от третото правило. Точност непроменена (медиана
  0.00 mm, 99.6% в 8 mm), ширина точно 1850.0, осемте метрики плоски, 23 доклада current.
  59 остават — това е честният остатък, а не 0.

- 2026-09-26 (3) — **Ревю на собствените ходове: една неточност в записа, един бъг в листа, и
  документът, който печатницата няма.** (1) В комита за люспите бях написал като факт, че „счупи го
  събирането на езичето" — **не съм го проверил**. По-вероятният механизъм е, че ъгловата люспа е
  отделен остров на черупката в собствената си клетка, свързан с останалото само през равнината на
  среза; сливането ѝ в „съседа с най-много лица" не я свързва, ако той не е клетката, през която тя
  се закача. Записът вече казва „не е установено". (2) `fit_test` вземаше ориентирите от **всички**
  върхове, включително вътрешното лице на стената и езичетата — „най-предна точка" на вътрешната
  страна на 3 mm черупка не е нещо, до което се мери. Сега само външната повърхност, със същия
  радиален тест като производството; три от шестте ориентира се преместиха. (3) В `03_PRINT/`
  имаше STL-и, матрица и CSV, и **нищо, което една печатница да прочете**: каква стена, какъв
  материал, какво да провери. Написано на ръка би остаряло за седмица — урокът от `check_reports`.
  Затова `panel_production` записва решенията и бройките като данни в `handoff.json`, а
  `print_qc` — последната стъпка, която знае QC резултата — генерира `03_PRINT/README.md` от тях.
  Двата файла са под надзор за възраст. **23 доклада current, 0 stale.**

- 2026-09-26 (2) — **28% от секциите са люспи, и моят опит да ги слея направи нещата по-лоши.**
  Измерено по целия комплект: **149 от 531 секции са под 40 mm** по най-голямото си измерение,
  а **68 са под 20**. Дванайсетмилиметрова люспа от 3 mm стена не е част — не се хваща, не се
  подравнява, не се лепи, и печатница, на която дадеш 149 такива, ще изгуби част от тях.
  Най-зле са `P21` (45), `P01` (18) и `P03/P04` (по 17).
  Причината не е бъг, а геометрия: **3D решетка върху тънка извита черупка оставя ъглова отломка
  във всяка клетка, която черупката само докосва**, и никаква стъпка не я премахва.
  **Опитът за сливане: 311 секции станаха 623, а 440 от тях под 60 mm.** Формата на грешката си
  струва да се запази. Сливането трябва да е на **групи клетки**, не чрез слепване на обекти,
  защото равнината между две слети клетки спира да е срез, а езиче, изтеглено там, би вдлъбнало
  жлеб в средата на непрекъснат панел — тази част беше вярна. Счупи го събирането на езичето: лице
  извън групата се приемаше, ако е в рамките на едно езиче от **коя да е** клетка на групата, а не
  от собствената ѝ външна граница — значи се дърпаше далечен материал, секциите излизаха несвързани
  и `loose_pieces` цепеше всяка на няколко.
  Върнато. **Истинският лек вероятно не е 3D решетка изобщо** — черупка иска рязане по двете си
  собствени повърхностни посоки, не по трите световни оси, и това е по-голяма промяна от сливане.
  Втори път днес моя поправка излиза по-лоша от проблема; и двата пъти я хвана мярка, а не око.

- 2026-09-26 — **Лявата и дясната страна на симетрична кола се режеха на различен брой части.**
  `P07 ROCKER_L` даваше **34 секции, `P08 ROCKER_R` — 18**, при идентични мешове (366 върха,
  314 лица, еднакъв bbox до 0.1 mm) и идентичен план за рязане (5 среза по X, 1 по Y).
  Причината е в теста за принадлежност към клетка: клетка взима лицата на съседа си като **езиче
  само в ПОЛОЖИТЕЛНАТА посока на всяка ос** — `hi <= cc < hi + tab`. Тази посока е абсолютна, значи
  отляво езичето стига навън, а отдясно навътре, и тънка клетка, която оцелява при
  `len(faces) < 3` от едната страна, отпада от другата.
  Да направя посоката относителна би пренаписало всеки съществуващ файл. Огледалото е и по-малка,
  и по-вярна промяна: колата е симетрична по построение, `panel_map` вече строи дясната половина
  като огледало на лявата, а две страни, които се различават, са производствена неприятност, не
  дизайн. **Дясната секция вече е огледало на лявата, а не втори независим срез.**
  Резултат: **12 от 12 огледални двойки съвпадат** (бяха 10 от 12). И странично, но същественo:
  **ширината на сглобеното пада 1852.2 → точно 1850.0** при заключени 1850 — тоест остатъкът от
  2.2 mm не беше „езичето по дизайн", както бях записал, а същата асиметрия, бутаща материал
  отвъд заключен размер отдясно. **Оттеглям обяснението от 21 септември.**

- 2026-09-26 — **`fit_test.py` — CLAUDE.md твърдо ограничение 6 най-после има съдържание.**
  „Не позволявай на собственика да пропусне fit-test на един отпечатан панел, преди да се печата
  останалото" стоеше като правило, но нищо не казваше какво МЕРИ тестът и какво значи да мине.
  Панелът е избран **от данните**: изцяло наш (значи лош резултат обвинява процеса, не липсващ
  скан), малък и евтин, с реална кривина в две посоки, в повече от една секция (иначе фугата с
  езиче остава непроверена) и на козметично прощаващо място. **`P39 ROCKER_END_L`** — 0.080 m²,
  0.30 kg, 3 секции, зад задното колело.
  Един печат отговаря на шест допускания, всяко от които е неотговорен въпрос от `docs/13`: държи
  ли 3 mm стена ламинат; държи ли езичето двете секции в линия; печата ли се на ориентацията, която
  веригата е избрала; заравят ли кит и боя характерните линии; колко свива материалът; и съвпада ли
  готовият ПАНЕЛ с проектната повърхност — `assembly_check` доказва, че ФАЙЛОВЕТЕ съвпадат до
  медиана 0.00 mm, което е друго твърдение.
  Мери се **с шублер и линия, без скенер**: шест ориентира, всеки краен по своята ос, тоест ъгъл
  или връх, върху който можеш да опреш челюст, и таблица с разстоянията между тях. Мери се на
  четири етапа и **промяната на всеки етап казва кой етап я е направил**.
  Какво значи „минава" **не се измисля**: допуск от никого няма (`docs/13` Q16), затова листът дава
  мащаба, който останалата работа вече допуска — фугите са 4 mm, фланецът 1 mm лепило, колата е
  заключена на 1850. Числата се записват и решението се взима с фирмата.

- 2026-09-21 — **Стопът — най-разпознаваемият елемент на задницата — не съществуваше в геометрията.**
  `docs/14` го заключва като *„тънко широко хоризонтално острие през задницата, с остри L-образни
  външни краища"* и изрично НЕ като триъгълна супер-кар лампа. Обвивките стояха в скелета от
  14 септември и `check_lighting` ги отчиташе като заградени — но **нищо не беше изрязано за тях**:
  `check_packaging` чете `TAIL_BAR` на **115.5 mm ПОД повърхността** и `TAIL_END` на 20.6. Това е
  вярно за кухина и безполезно без отвор.
  Построено по вече валидирания модел на фара: прорез до повърхността плюс корпус с 5 mm стена и
  6 mm въздух около модула, отворен назад, защото **E-маркираният модул не се пипа**. Всички числа
  идват от LOCKED обвивките — `TAIL_BAR` specX 3200, 45×1440×38; `TAIL_END` 3120, ±700, 120×40×38 —
  не от преценка. Одит: **21/2/13/6 → 23 PROCEED / 2 / 13 / 4.**
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

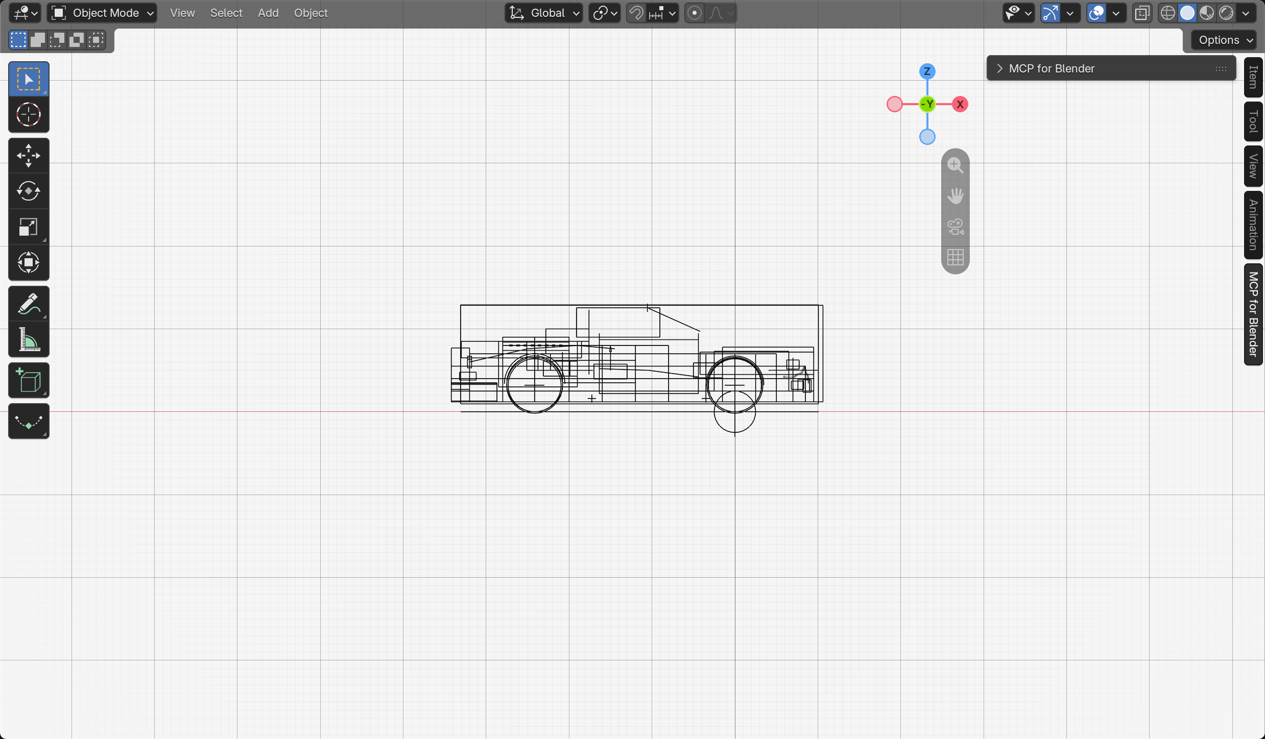
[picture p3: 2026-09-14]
04_ENGINEERING/statev_v01/review/01_side.png

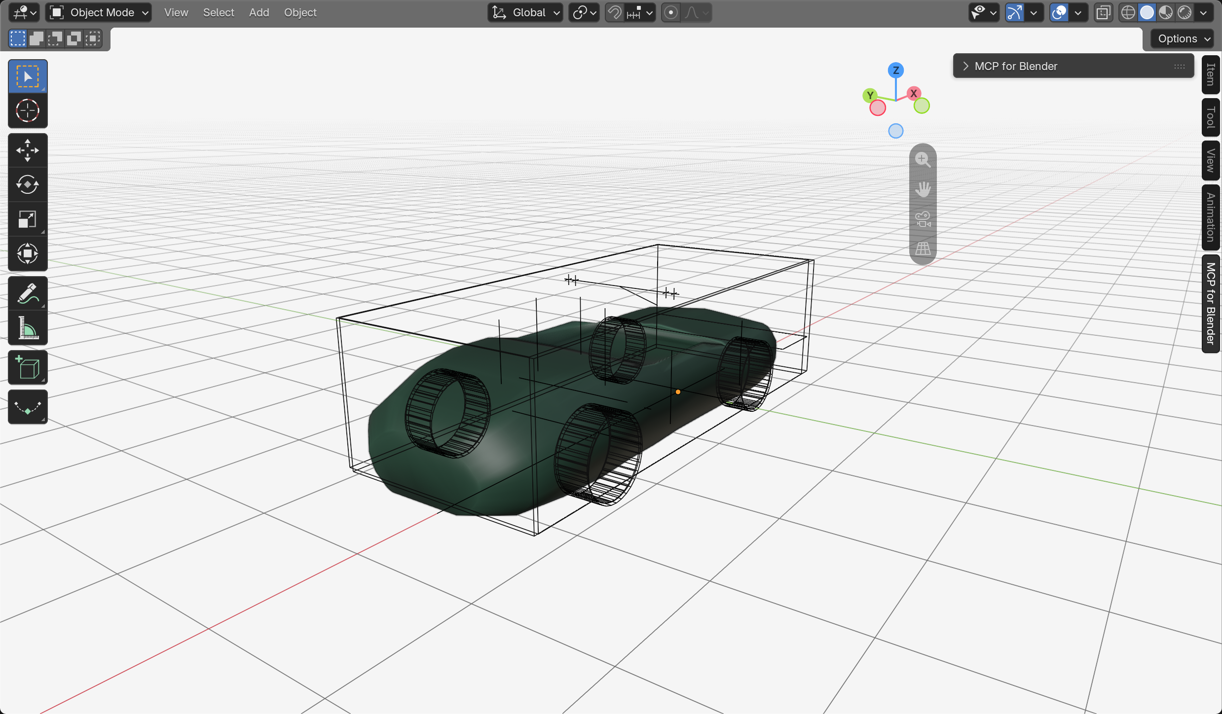
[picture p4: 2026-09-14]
04_ENGINEERING/statev_v01/review/11_preview_front34.png

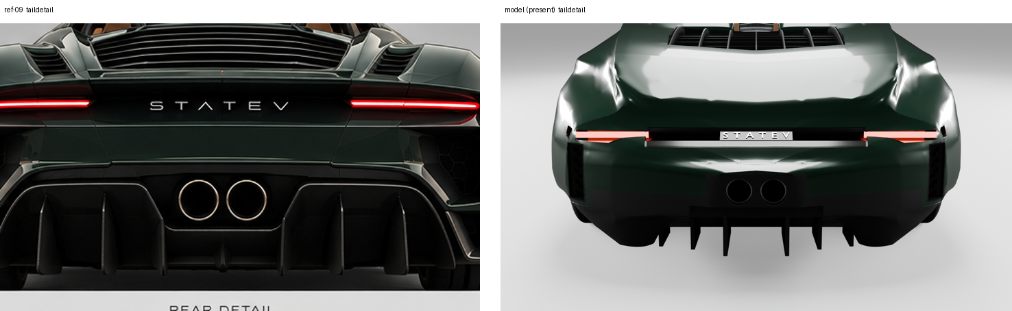
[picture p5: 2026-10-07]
04_ENGINEERING/statev_v01/review/sheets/present/sheet_taildetail.png

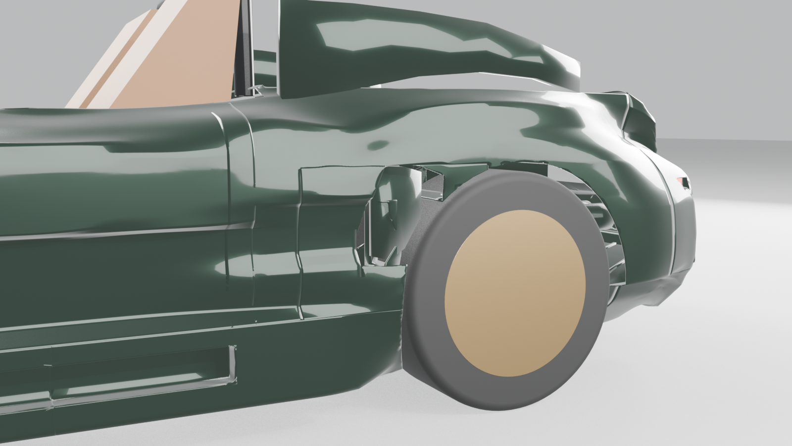
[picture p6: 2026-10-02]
04_ENGINEERING/statev_v01/review/rv_glossy_files_intake.png

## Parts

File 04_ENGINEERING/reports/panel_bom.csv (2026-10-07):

ID | NAME | SIDE | DESIGN_GROUP | ASSEMBLY_STEP | INSTALL_VECTOR | MANUFACTURING_METHOD | MATERIAL | NOMINAL_THICKNESS_MM | PANEL_GAP_MM | FLANGE_WIDTH_MM | OVERLAP_MM | STATUS | LENGTH | WIDTH | HEIGHT | VOLUME | ESTIMATED_MASS | MOUNT_COUNT | PRINT_SPLIT_COUNT | FINISH | FINISH_ZONES
P01 | FRONT_FASCIA | - | FRONT | 3 | +X | printed master -> composite | GRP composite | 2.5 | 4.0 | 20-35 | 10-20 | RED | NEEDS_GEOMETRY | NEEDS_GEOMETRY | NEEDS_GEOMETRY | NEEDS_GEOMETRY | NEEDS_GEOMETRY | NEEDS_GEOMETRY | NEEDS_BUILD_VOLUME | paint | gloss black below_drl 12 mm (below the DRL groove, as ref-09's front)
P28 | FRONT_SPLITTER_L | L | FRONT | 4 | +Z | printed master -> composite | GRP composite | 2.5 | 4.0 | 20-35 | 10-20 | RED | NEEDS_GEOMETRY | NEEDS_GEOMETRY | NEEDS_GEOMETRY | NEEDS_GEOMETRY | NEEDS_GEOMETRY | NEEDS_GEOMETRY | NEEDS_BUILD_VOLUME | carbon
P41 | FRONT_SPLITTER_R | R | FRONT | 4 | +Z | printed master -> composite | GRP composite | 2.5 | 4.0 | 20-35 | 10-20 | RED | NEEDS_GEOMETRY | NEEDS_GEOMETRY | NEEDS_GEOMETRY | NEEDS_GEOMETRY | NEEDS_GEOMETRY | NEEDS_GEOMETRY | NEEDS_BUILD_VOLUME | carbon
P43 | FRONT_MASK | - | FRONT | 4 | +X | direct print | PETG | 2.5 | 4.0 | 20-35 | 10-20 | RED | NEEDS_GEOMETRY | NEEDS_GEOMETRY | NEEDS_GEOMETRY | NEEDS_GEOMETRY | NEEDS_GEOMETRY | NEEDS_GEOMETRY | NEEDS_BUILD_VOLUME | gloss black
P54 | CORNER_GRILLE_L | L | FRONT | 4 | +X | direct print | PETG | 2.5 | 4.0 | 20-35 | 10-20 | RED | NEEDS_GEOMETRY | NEEDS_GEOMETRY | NEEDS_GEOMETRY | NEEDS_GEOMETRY | NEEDS_GEOMETRY | NEEDS_GEOMETRY | NEEDS_BUILD_VOLUME | gloss black
P55 | CORNER_GRILLE_R | R | FRONT | 4 | +X | direct print | PETG | 2.5 | 4.0 | 20-35 | 10-20 | RED | NEEDS_GEOMETRY | NEEDS_GEOMETRY | NEEDS_GEOMETRY | NEEDS_GEOMETRY | NEEDS_GEOMETRY | NEEDS_GEOMETRY | NEEDS_BUILD_VOLUME | gloss black
P02 | HOOD | - | FRONT | 5 | -Z | printed master -> composite | GRP composite | 2.5 | 4.0 | 20-35 | 10-20 | YELLOW | NEEDS_GEOMETRY | NEEDS_GEOMETRY | NEEDS_GEOMETRY | NEEDS_GEOMETRY | NEEDS_GEOMETRY | NEEDS_GEOMETRY | NEEDS_BUILD_VOLUME | paint
P03 | FRONT_FENDER_L | L | FRONT | 5 | -Y | printed master -> composite | GRP composite | 2.5 | 4.0 | 20-35 | 10-20 | YELLOW | NEEDS_GEOMETRY | NEEDS_GEOMETRY | NEEDS_GEOMETRY | NEEDS_GEOMETRY | NEEDS_GEOMETRY | NEEDS_GEOMETRY | NEEDS_BUILD_VOLUME | paint
P04 | FRONT_FENDER_R | R | FRONT | 5 | +Y | printed master -> composite | GRP composite | 2.5 | 4.0 | 20-35 | 10-20 | YELLOW | NEEDS_GEOMETRY | NEEDS_GEOMETRY | NEEDS_GEOMETRY | NEEDS_GEOMETRY | NEEDS_GEOMETRY | NEEDS_GEOMETRY | NEEDS_BUILD_VOLUME | paint
P05 | FENDER_CHANNEL_L | L | FRONT | 6 | -Y | direct print | PETG | 2.5 | 4.0 | 20-35 | 10-20 | YELLOW | NEEDS_GEOMETRY | NEEDS_GEOMETRY | NEEDS_GEOMETRY | NEEDS_GEOMETRY | NEEDS_GEOMETRY | NEEDS_GEOMETRY | NEEDS_BUILD_VOLUME | gloss black
P06 | FENDER_CHANNEL_R | R | FRONT | 6 | +Y | direct print | PETG | 2.5 | 4.0 | 20-35 | 10-20 | YELLOW | NEEDS_GEOMETRY | NEEDS_GEOMETRY | NEEDS_GEOMETRY | NEEDS_GEOMETRY | NEEDS_GEOMETRY | NEEDS_GEOMETRY | NEEDS_BUILD_VOLUME | gloss black
P07 | ROCKER_L | L | SIDE | 8 | -Y | printed master -> composite | GRP composite | 2.5 | 4.0 | 20-35 | 10-20 | YELLOW | NEEDS_GEOMETRY | NEEDS_GEOMETRY | NEEDS_GEOMETRY | NEEDS_GEOMETRY | NEEDS_GEOMETRY | NEEDS_GEOMETRY | NEEDS_BUILD_VOLUME | carbon
P08 | ROCKER_R | R | SIDE | 8 | +Y | printed master -> composite | GRP composite | 2.5 | 4.0 | 20-35 | 10-20 | YELLOW | NEEDS_GEOMETRY | NEEDS_GEOMETRY | NEEDS_GEOMETRY | NEEDS_GEOMETRY | NEEDS_GEOMETRY | NEEDS_GEOMETRY | NEEDS_BUILD_VOLUME | carbon
P39 | ROCKER_END_L | L | SIDE | 8 | -Y | printed master -> composite | GRP composite | 2.5 | 4.0 | 20-35 | 10-20 | YELLOW | NEEDS_GEOMETRY | NEEDS_GEOMETRY | NEEDS_GEOMETRY | NEEDS_GEOMETRY | NEEDS_GEOMETRY | NEEDS_GEOMETRY | NEEDS_BUILD_VOLUME | carbon
P40 | ROCKER_END_R | R | SIDE | 8 | +Y | printed master -> composite | GRP composite | 2.5 | 4.0 | 20-35 | 10-20 | YELLOW | NEEDS_GEOMETRY | NEEDS_GEOMETRY | NEEDS_GEOMETRY | NEEDS_GEOMETRY | NEEDS_GEOMETRY | NEEDS_GEOMETRY | NEEDS_BUILD_VOLUME | carbon
P09 | DOOR_SKIN_L | L | SIDE | 9 | -Y | printed master -> composite | GRP composite | 2.5 | 4.0 | 20-35 | 10-20 | YELLOW | NEEDS_GEOMETRY | NEEDS_GEOMETRY | NEEDS_GEOMETRY | NEEDS_GEOMETRY | NEEDS_GEOMETRY | NEEDS_GEOMETRY | NEEDS_BUILD_VOLUME | paint
P10 | DOOR_SKIN_R | R | SIDE | 9 | +Y | printed master -> composite | GRP composite | 2.5 | 4.0 | 20-35 | 10-20 | YELLOW | NEEDS_GEOMETRY | NEEDS_GEOMETRY | NEEDS_GEOMETRY | NEEDS_GEOMETRY | NEEDS_GEOMETRY | NEEDS_GEOMETRY | NEEDS_BUILD_VOLUME | paint
P37 | MIRROR_CAP_L | L | SIDE | 10 | -Y | direct print, ASA | ASA | 2.5 | 4.0 | 20-35 | 10-20 | YELLOW | NEEDS_GEOMETRY | NEEDS_GEOMETRY | NEEDS_GEOMETRY | NEEDS_GEOMETRY | NEEDS_GEOMETRY | NEEDS_GEOMETRY | NEEDS_BUILD_VOLUME | paint
P38 | MIRROR_CAP_R | R | SIDE | 10 | +Y | direct print, ASA | ASA | 2.5 | 4.0 | 20-35 | 10-20 | YELLOW | NEEDS_GEOMETRY | NEEDS_GEOMETRY | NEEDS_GEOMETRY | NEEDS_GEOMETRY | NEEDS_GEOMETRY | NEEDS_GEOMETRY | NEEDS_BUILD_VOLUME | paint
P11 | SIDE_INTAKE_L | L | SIDE | 11 | -Y | printed master -> composite | GRP composite | 2.5 | 4.0 | 20-35 | 10-20 | RED | NEEDS_GEOMETRY | NEEDS_GEOMETRY | NEEDS_GEOMETRY | NEEDS_GEOMETRY | NEEDS_GEOMETRY | NEEDS_GEOMETRY | NEEDS_BUILD_VOLUME | paint
P12 | SIDE_INTAKE_R | R | SIDE | 11 | +Y | printed master -> composite | GRP composite | 2.5 | 4.0 | 20-35 | 10-20 | RED | NEEDS_GEOMETRY | NEEDS_GEOMETRY | NEEDS_GEOMETRY | NEEDS_GEOMETRY | NEEDS_GEOMETRY | NEEDS_GEOMETRY | NEEDS_BUILD_VOLUME | paint
P31 | INTAKE_DUCT_L | L | SIDE | 12 | -Y | direct print | PETG | 2.5 | 4.0 | 20-35 | 10-20 | RED | NEEDS_GEOMETRY | NEEDS_GEOMETRY | NEEDS_GEOMETRY | NEEDS_GEOMETRY | NEEDS_GEOMETRY | NEEDS_GEOMETRY | NEEDS_BUILD_VOLUME | hidden
P32 | INTAKE_DUCT_R | R | SIDE | 12 | +Y | direct print | PETG | 2.5 | 4.0 | 20-35 | 10-20 | RED | NEEDS_GEOMETRY | NEEDS_GEOMETRY | NEEDS_GEOMETRY | NEEDS_GEOMETRY | NEEDS_GEOMETRY | NEEDS_GEOMETRY | NEEDS_BUILD_VOLUME | hidden
P13 | INTAKE_BLADE_L | L | SIDE | 13 | -Y | direct print or CNC | PETG | 2.5 | 4.0 | 20-35 | 10-20 | RED | NEEDS_GEOMETRY | NEEDS_GEOMETRY | NEEDS_GEOMETRY | NEEDS_GEOMETRY | NEEDS_GEOMETRY | NEEDS_GEOMETRY | NEEDS_BUILD_VOLUME | carbon
P14 | INTAKE_BLADE_R | R | SIDE | 13 | +Y | direct print or CNC | PETG | 2.5 | 4.0 | 20-35 | 10-20 | RED | NEEDS_GEOMETRY | NEEDS_GEOMETRY | NEEDS_GEOMETRY | NEEDS_GEOMETRY | NEEDS_GEOMETRY | NEEDS_GEOMETRY | NEEDS_BUILD_VOLUME | carbon
P15 | REAR_HAUNCH_L | L | REAR | 14 | -Y | printed master -> composite | GRP composite | 2.5 | 4.0 | 20-35 | 10-20 | RED | NEEDS_GEOMETRY | NEEDS_GEOMETRY | NEEDS_GEOMETRY | NEEDS_GEOMETRY | NEEDS_GEOMETRY | NEEDS_GEOMETRY | NEEDS_BUILD_VOLUME | paint
P16 | REAR_HAUNCH_R | R | REAR | 14 | +Y | printed master -> composite | GRP composite | 2.5 | 4.0 | 20-35 | 10-20 | RED | NEEDS_GEOMETRY | NEEDS_GEOMETRY | NEEDS_GEOMETRY | NEEDS_GEOMETRY | NEEDS_GEOMETRY | NEEDS_GEOMETRY | NEEDS_BUILD_VOLUME | paint
P63 | SEAT_HUMP_L | L | REAR | 16 | -Z | printed master -> composite | GRP composite | 2.5 | 4.0 | 20-35 | 10-20 | RED | NEEDS_GEOMETRY | NEEDS_GEOMETRY | NEEDS_GEOMETRY | NEEDS_GEOMETRY | NEEDS_GEOMETRY | NEEDS_GEOMETRY | NEEDS_BUILD_VOLUME | paint
P64 | SEAT_HUMP_R | R | REAR | 16 | -Z | printed master -> composite | GRP composite | 2.5 | 4.0 | 20-35 | 10-20 | RED | NEEDS_GEOMETRY | NEEDS_GEOMETRY | NEEDS_GEOMETRY | NEEDS_GEOMETRY | NEEDS_GEOMETRY | NEEDS_GEOMETRY | NEEDS_BUILD_VOLUME | paint
P19 | REAR_DECK_L | L | REAR | 16 | -Z | printed master -> composite | GRP composite | 2.5 | 4.0 | 20-35 | 10-20 | RED | NEEDS_GEOMETRY | NEEDS_GEOMETRY | NEEDS_GEOMETRY | NEEDS_GEOMETRY | NEEDS_GEOMETRY | NEEDS_GEOMETRY | NEEDS_BUILD_VOLUME | paint
P42 | REAR_DECK_R | R | REAR | 16 | -Z | printed master -> composite | GRP composite | 2.5 | 4.0 | 20-35 | 10-20 | RED | NEEDS_GEOMETRY | NEEDS_GEOMETRY | NEEDS_GEOMETRY | NEEDS_GEOMETRY | NEEDS_GEOMETRY | NEEDS_GEOMETRY | NEEDS_BUILD_VOLUME | paint
P20 | ENGINE_COVER | - | REAR | 17 | -Z | printed master -> composite | GRP composite | 2.5 | 4.0 | 20-35 | 10-20 | RED | NEEDS_GEOMETRY | NEEDS_GEOMETRY | NEEDS_GEOMETRY | NEEDS_GEOMETRY | NEEDS_GEOMETRY | NEEDS_GEOMETRY | NEEDS_BUILD_VOLUME | paint
P33 | ENGINE_COVER_LOUVRES | - | REAR | 18 | -Z | direct print | PETG | 2.5 | 4.0 | 20-35 | 10-20 | RED | NEEDS_GEOMETRY | NEEDS_GEOMETRY | NEEDS_GEOMETRY | NEEDS_GEOMETRY | NEEDS_GEOMETRY | NEEDS_GEOMETRY | NEEDS_BUILD_VOLUME | carbon
P21 | REAR_FASCIA | - | REAR | 19 | -X | printed master -> composite | GRP composite | 2.5 | 4.0 | 20-35 | 10-20 | YELLOW | NEEDS_GEOMETRY | NEEDS_GEOMETRY | NEEDS_GEOMETRY | NEEDS_GEOMETRY | NEEDS_GEOMETRY | NEEDS_GEOMETRY | NEEDS_BUILD_VOLUME | paint
P22 | DIFFUSER | - | REAR | 22 | -X | printed master -> composite | GRP composite | 2.5 | 4.0 | 20-35 | 10-20 | RED | NEEDS_GEOMETRY | NEEDS_GEOMETRY | NEEDS_GEOMETRY | NEEDS_GEOMETRY | NEEDS_GEOMETRY | NEEDS_GEOMETRY | NEEDS_BUILD_VOLUME | carbon
P56 | TAIL_VENT_GRILLE_L | L | REAR | 20 | -X | direct print | PETG | 2.5 | 4.0 | 20-35 | 10-20 | YELLOW | NEEDS_GEOMETRY | NEEDS_GEOMETRY | NEEDS_GEOMETRY | NEEDS_GEOMETRY | NEEDS_GEOMETRY | NEEDS_GEOMETRY | NEEDS_BUILD_VOLUME | gloss black
P57 | TAIL_VENT_GRILLE_R | R | REAR | 20 | -X | direct print | PETG | 2.5 | 4.0 | 20-35 | 10-20 | YELLOW | NEEDS_GEOMETRY | NEEDS_GEOMETRY | NEEDS_GEOMETRY | NEEDS_GEOMETRY | NEEDS_GEOMETRY | NEEDS_GEOMETRY | NEEDS_BUILD_VOLUME | gloss black
P44 | DIFFUSER_FIN_INNER_L | L | REAR | 23 | -Z | direct print | PETG | 2.5 | 4.0 | 20-35 | 10-20 | RED | NEEDS_GEOMETRY | NEEDS_GEOMETRY | NEEDS_GEOMETRY | NEEDS_GEOMETRY | NEEDS_GEOMETRY | NEEDS_GEOMETRY | NEEDS_BUILD_VOLUME | carbon
P45 | DIFFUSER_FIN_INNER_R | R | REAR | 23 | -Z | direct print | PETG | 2.5 | 4.0 | 20-35 | 10-20 | RED | NEEDS_GEOMETRY | NEEDS_GEOMETRY | NEEDS_GEOMETRY | NEEDS_GEOMETRY | NEEDS_GEOMETRY | NEEDS_GEOMETRY | NEEDS_BUILD_VOLUME | carbon
P46 | DIFFUSER_FIN_OUTER_L | L | REAR | 23 | -Z | direct print | PETG | 2.5 | 4.0 | 20-35 | 10-20 | RED | NEEDS_GEOMETRY | NEEDS_GEOMETRY | NEEDS_GEOMETRY | NEEDS_GEOMETRY | NEEDS_GEOMETRY | NEEDS_GEOMETRY | NEEDS_BUILD_VOLUME | carbon
P47 | DIFFUSER_FIN_OUTER_R | R | REAR | 23 | -Z | direct print | PETG | 2.5 | 4.0 | 20-35 | 10-20 | RED | NEEDS_GEOMETRY | NEEDS_GEOMETRY | NEEDS_GEOMETRY | NEEDS_GEOMETRY | NEEDS_GEOMETRY | NEEDS_GEOMETRY | NEEDS_BUILD_VOLUME | carbon
P58 | DIFFUSER_FIN_EDGE_L | L | REAR | 23 | -Z | direct print | PETG | 2.5 | 4.0 | 20-35 | 10-20 | RED | NEEDS_GEOMETRY | NEEDS_GEOMETRY | NEEDS_GEOMETRY | NEEDS_GEOMETRY | NEEDS_GEOMETRY | NEEDS_GEOMETRY | NEEDS_BUILD_VOLUME | carbon
P59 | DIFFUSER_FIN_EDGE_R | R | REAR | 23 | -Z | direct print | PETG | 2.5 | 4.0 | 20-35 | 10-20 | RED | NEEDS_GEOMETRY | NEEDS_GEOMETRY | NEEDS_GEOMETRY | NEEDS_GEOMETRY | NEEDS_GEOMETRY | NEEDS_GEOMETRY | NEEDS_BUILD_VOLUME | carbon
P61 | SPLITTER_END_L | L | FRONT | 4 | +X | direct print | PETG | 2.5 | 4.0 | 20-35 | 10-20 | RED | NEEDS_GEOMETRY | NEEDS_GEOMETRY | NEEDS_GEOMETRY | NEEDS_GEOMETRY | NEEDS_GEOMETRY | NEEDS_GEOMETRY | NEEDS_BUILD_VOLUME | carbon
P62 | SPLITTER_END_R | R | FRONT | 4 | +X | direct print | PETG | 2.5 | 4.0 | 20-35 | 10-20 | RED | NEEDS_GEOMETRY | NEEDS_GEOMETRY | NEEDS_GEOMETRY | NEEDS_GEOMETRY | NEEDS_GEOMETRY | NEEDS_GEOMETRY | NEEDS_BUILD_VOLUME | carbon
P60 | BADGE_REAR | - | REAR | 21 | -X | direct print | PETG | 2.5 | 4.0 | 20-35 | 10-20 | YELLOW | NEEDS_GEOMETRY | NEEDS_GEOMETRY | NEEDS_GEOMETRY | NEEDS_GEOMETRY | NEEDS_GEOMETRY | NEEDS_GEOMETRY | NEEDS_BUILD_VOLUME | satin silver
P24 | HEADLIGHT_HOUSING_L | L | LIGHTS | 25 | +X | direct print, ASA | ASA | 2.5 | 4.0 | 20-35 | 10-20 | YELLOW | NEEDS_GEOMETRY | NEEDS_GEOMETRY | NEEDS_GEOMETRY | NEEDS_GEOMETRY | NEEDS_GEOMETRY | NEEDS_GEOMETRY | NEEDS_BUILD_VOLUME | gloss black
P65 | EYE_BEZEL_IN_L | L | LIGHTS | 25 | +X | direct print, ASA | ASA | 2.5 | 4.0 | 20-35 | 10-20 | YELLOW | NEEDS_GEOMETRY | NEEDS_GEOMETRY | NEEDS_GEOMETRY | NEEDS_GEOMETRY | NEEDS_GEOMETRY | NEEDS_GEOMETRY | NEEDS_BUILD_VOLUME | gloss black
P66 | EYE_BEZEL_IN_R | R | LIGHTS | 25 | +X | direct print, ASA | ASA | 2.5 | 4.0 | 20-35 | 10-20 | YELLOW | NEEDS_GEOMETRY | NEEDS_GEOMETRY | NEEDS_GEOMETRY | NEEDS_GEOMETRY | NEEDS_GEOMETRY | NEEDS_GEOMETRY | NEEDS_BUILD_VOLUME | gloss black
P67 | EYE_BEZEL_OUT_L | L | LIGHTS | 25 | +X | direct print, ASA | ASA | 2.5 | 4.0 | 20-35 | 10-20 | YELLOW | NEEDS_GEOMETRY | NEEDS_GEOMETRY | NEEDS_GEOMETRY | NEEDS_GEOMETRY | NEEDS_GEOMETRY | NEEDS_GEOMETRY | NEEDS_BUILD_VOLUME | gloss black
P68 | EYE_BEZEL_OUT_R | R | LIGHTS | 25 | +X | direct print, ASA | ASA | 2.5 | 4.0 | 20-35 | 10-20 | YELLOW | NEEDS_GEOMETRY | NEEDS_GEOMETRY | NEEDS_GEOMETRY | NEEDS_GEOMETRY | NEEDS_GEOMETRY | NEEDS_GEOMETRY | NEEDS_BUILD_VOLUME | gloss black
P69 | EYE_COVER_L | L | LIGHTS | 26 | +X | thermoformed clear PC over a printed buck | polycarbonate, clear | 2.5 | 4.0 | 20-35 | 10-20 | YELLOW | NEEDS_GEOMETRY | NEEDS_GEOMETRY | NEEDS_GEOMETRY | NEEDS_GEOMETRY | NEEDS_GEOMETRY | NEEDS_GEOMETRY | NEEDS_BUILD_VOLUME | clear
P70 | EYE_COVER_R | R | LIGHTS | 26 | +X | thermoformed clear PC over a printed buck | polycarbonate, clear | 2.5 | 4.0 | 20-35 | 10-20 | YELLOW | NEEDS_GEOMETRY | NEEDS_GEOMETRY | NEEDS_GEOMETRY | NEEDS_GEOMETRY | NEEDS_GEOMETRY | NEEDS_GEOMETRY | NEEDS_BUILD_VOLUME | clear
P25 | HEADLIGHT_HOUSING_R | R | LIGHTS | 25 | +X | direct print, ASA | ASA | 2.5 | 4.0 | 20-35 | 10-20 | YELLOW | NEEDS_GEOMETRY | NEEDS_GEOMETRY | NEEDS_GEOMETRY | NEEDS_GEOMETRY | NEEDS_GEOMETRY | NEEDS_GEOMETRY | NEEDS_BUILD_VOLUME | gloss black
P26 | TAIL_HOUSING_L | L | LIGHTS | 26 | -X | direct print, ASA | ASA | 2.5 | 4.0 | 20-35 | 10-20 | YELLOW | NEEDS_GEOMETRY | NEEDS_GEOMETRY | NEEDS_GEOMETRY | NEEDS_GEOMETRY | NEEDS_GEOMETRY | NEEDS_GEOMETRY | NEEDS_BUILD_VOLUME | hidden
P27 | TAIL_HOUSING_R | R | LIGHTS | 26 | -X | direct print, ASA | ASA | 2.5 | 4.0 | 20-35 | 10-20 | YELLOW | NEEDS_GEOMETRY | NEEDS_GEOMETRY | NEEDS_GEOMETRY | NEEDS_GEOMETRY | NEEDS_GEOMETRY | NEEDS_GEOMETRY | NEEDS_BUILD_VOLUME | hidden

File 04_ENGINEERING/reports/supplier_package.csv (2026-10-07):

PART | NAME | SIDE | GROUP | ASSEMBLY_STEP | INSTALL_VECTOR | METHOD | STATUS | OFFER | LENGTH_MM | WIDTH_MM | HEIGHT_MM | SKIN_AREA_M2 | PIECES | CORE_WALL_MM | CORE_VOLUME_CM3 | CORE_MASS_KG | CORE_MASS_BASIS | INFILL | PRINT_MATERIAL | SPLIT | SPLIT_INTENT | PRINT_ORIENTATION | FLANGE_WIDTH | PANEL_GAP | EXOTHERM | DONOR_INTERFACE | SCAN_DEPENDENCY | BOUNDARY_DONOR_DEPENDENT | BOUNDED_BY | TRIM_ALLOWANCE | PROOF | STL
P05 | FENDER_CHANNEL_L | L | FRONT | 6 | -Y | direct print | PROCEED | quote this now | 380.0 | 134.0 | 98.6 | 0.296 | 1 | PROVISIONAL 3.0 — Q30: minimum printed wall for a laminating core | 888.2 | 1.1 | PROVISIONAL: 3.0 mm wall x 1.24 g/cm3. Neither is a quote. | UNKNOWN Q37: infill pattern and density for a core that will be laminated | UNKNOWN Q29: print material the shop will accept under its resin | UNKNOWN Q26: usable build volume, not the catalogue figure | single piece on any machine | UNKNOWN Q32: maximum unsupported overhang | UNKNOWN Q15: bonding flange width | UNKNOWN Q16: panel gap the shop works to | UNKNOWN Q28: resin exotherm against the print's heat deflection temperature | fender mounting points, wheelhouse liner and its clearance, steering lock envelope — the kingpin axis is unknown, so the swept volume is a worst case | datum only |  |  | PROVISIONAL 15 mm | only our own data and published donor values reach it | 03_PRINT/production/P05_FENDER_CHANNEL_L_whole.stl
P06 | FENDER_CHANNEL_R | R | FRONT | 6 | +Y | direct print | PROCEED | quote this now | 380.0 | 134.0 | 98.6 | 0.296 | 1 | PROVISIONAL 3.0 — Q30: minimum printed wall for a laminating core | 888.2 | 1.1 | PROVISIONAL: 3.0 mm wall x 1.24 g/cm3. Neither is a quote. | UNKNOWN Q37: infill pattern and density for a core that will be laminated | UNKNOWN Q29: print material the shop will accept under its resin | UNKNOWN Q26: usable build volume, not the catalogue figure | single piece on any machine | UNKNOWN Q32: maximum unsupported overhang | UNKNOWN Q15: bonding flange width | UNKNOWN Q16: panel gap the shop works to | UNKNOWN Q28: resin exotherm against the print's heat deflection temperature | fender mounting points, wheelhouse liner and its clearance, steering lock envelope — the kingpin axis is unknown, so the swept volume is a worst case | datum only |  |  | PROVISIONAL 15 mm | only our own data and published donor values reach it | 03_PRINT/production/P06_FENDER_CHANNEL_R_whole.stl
P07 | ROCKER_L | L | SIDE | 8 | -Y | printed master -> composite | PROCEED | quote this now | 1807.5 | 135.1 | 206.1 | 0.413 | 1 | PROVISIONAL 3.0 — Q30: minimum printed wall for a laminating core | 1238.8 | 1.54 | PROVISIONAL: 3.0 mm wall x 1.24 g/cm3. Neither is a quote. | UNKNOWN Q37: infill pattern and density for a core that will be laminated | UNKNOWN Q29: print material the shop will accept under its resin | UNKNOWN Q26: usable build volume, not the catalogue figure | splits at the door shut line | UNKNOWN Q32: maximum unsupported overhang | UNKNOWN Q15: bonding flange width | UNKNOWN Q16: panel gap the shop works to | UNKNOWN Q28: resin exotherm against the print's heat deflection temperature | sill profile and where a bonded flange can land, jack point access after the panel is on | datum only | no |  | PROVISIONAL 15 mm | measured: no approx donor value moves its boundary, and the cabin cut -- the only thing cowl_x and hoop_x reshape -- does not reach it | 03_PRINT/pilot_P07/P07_ROCKER_L_core_PROVISIONAL.stl
P08 | ROCKER_R | R | SIDE | 8 | +Y | printed master -> composite | PROCEED | quote this now | 1807.5 | 135.1 | 206.1 | 0.413 | 1 | PROVISIONAL 3.0 — Q30: minimum printed wall for a laminating core | 1238.8 | 1.54 | PROVISIONAL: 3.0 mm wall x 1.24 g/cm3. Neither is a quote. | UNKNOWN Q37: infill pattern and density for a core that will be laminated | UNKNOWN Q29: print material the shop will accept under its resin | UNKNOWN Q26: usable build volume, not the catalogue figure | splits at the door shut line | UNKNOWN Q32: maximum unsupported overhang | UNKNOWN Q15: bonding flange width | UNKNOWN Q16: panel gap the shop works to | UNKNOWN Q28: resin exotherm against the print's heat deflection temperature | sill profile and where a bonded flange can land, jack point access after the panel is on | datum only | no |  | PROVISIONAL 15 mm | measured: no approx donor value moves its boundary, and the cabin cut -- the only thing cowl_x and hoop_x reshape -- does not reach it | 03_PRINT/pilot_P08/P08_ROCKER_R_core_PROVISIONAL.stl
P13 | INTAKE_BLADE_L | L | SIDE | 13 | -Y | direct print or CNC | PROCEED | quote this now | 165.0 | 16.0 | 340.0 | 0.053 | 1 | PROVISIONAL 3.0 — Q30: minimum printed wall for a laminating core | 160.3 | 0.2 | PROVISIONAL: 3.0 mm wall x 1.24 g/cm3. Neither is a quote. | UNKNOWN Q37: infill pattern and density for a core that will be laminated | UNKNOWN Q29: print material the shop will accept under its resin | UNKNOWN Q26: usable build volume, not the catalogue figure | single piece | UNKNOWN Q32: maximum unsupported overhang | UNKNOWN Q15: bonding flange width | UNKNOWN Q16: panel gap the shop works to | UNKNOWN Q28: resin exotherm against the print's heat deflection temperature | the real opening's shape, not just its X, duct route from the opening to the plenum, what is behind the opening on this particular car | datum only |  |  | PROVISIONAL 15 mm | only our own data and published donor values reach it | 03_PRINT/production/P13_INTAKE_BLADE_L_whole.stl
P14 | INTAKE_BLADE_R | R | SIDE | 13 | +Y | direct print or CNC | PROCEED | quote this now | 165.0 | 16.0 | 340.0 | 0.053 | 1 | PROVISIONAL 3.0 — Q30: minimum printed wall for a laminating core | 160.3 | 0.2 | PROVISIONAL: 3.0 mm wall x 1.24 g/cm3. Neither is a quote. | UNKNOWN Q37: infill pattern and density for a core that will be laminated | UNKNOWN Q29: print material the shop will accept under its resin | UNKNOWN Q26: usable build volume, not the catalogue figure | single piece | UNKNOWN Q32: maximum unsupported overhang | UNKNOWN Q15: bonding flange width | UNKNOWN Q16: panel gap the shop works to | UNKNOWN Q28: resin exotherm against the print's heat deflection temperature | the real opening's shape, not just its X, duct route from the opening to the plenum, what is behind the opening on this particular car | datum only |  |  | PROVISIONAL 15 mm | only our own data and published donor values reach it | 03_PRINT/production/P14_INTAKE_BLADE_R_whole.stl
P24 | HEADLIGHT_HOUSING_L | L | LIGHTS | 25 | +X | direct print, ASA | PROCEED | quote this now | 172.0 | 122.0 | 122.0 | 0.184 | 1 | PROVISIONAL 3.0 — Q30: minimum printed wall for a laminating core | 551.7 | 0.68 | PROVISIONAL: 3.0 mm wall x 1.24 g/cm3. Neither is a quote. | UNKNOWN Q37: infill pattern and density for a core that will be laminated | UNKNOWN Q29: print material the shop will accept under its resin | UNKNOWN Q26: usable build volume, not the catalogue figure | single piece | UNKNOWN Q32: maximum unsupported overhang | UNKNOWN Q15: bonding flange width | UNKNOWN Q16: panel gap the shop works to | UNKNOWN Q28: resin exotherm against the print's heat deflection temperature | the front structure the housing bolts to, beam aim check on the real car | datum only |  |  | PROVISIONAL 15 mm | only our own data and published donor values reach it | 03_PRINT/production/P24_HEADLIGHT_HOUSING_L_whole.stl
P25 | HEADLIGHT_HOUSING_R | R | LIGHTS | 25 | +X | direct print, ASA | PROCEED | quote this now | 172.0 | 122.0 | 122.0 | 0.184 | 1 | PROVISIONAL 3.0 — Q30: minimum printed wall for a laminating core | 552.0 | 0.68 | PROVISIONAL: 3.0 mm wall x 1.24 g/cm3. Neither is a quote. | UNKNOWN Q37: infill pattern and density for a core that will be laminated | UNKNOWN Q29: print material the shop will accept under its resin | UNKNOWN Q26: usable build volume, not the catalogue figure | single piece | UNKNOWN Q32: maximum unsupported overhang | UNKNOWN Q15: bonding flange width | UNKNOWN Q16: panel gap the shop works to | UNKNOWN Q28: resin exotherm against the print's heat deflection temperature | the front structure the housing bolts to, beam aim check on the real car | datum only |  |  | PROVISIONAL 15 mm | only our own data and published donor values reach it | 03_PRINT/production/P25_HEADLIGHT_HOUSING_R_whole.stl
P39 | ROCKER_END_L | L | SIDE | 8 | -Y | printed master -> composite | PROCEED | quote this now | 153.8 | 292.7 | 202.5 | 0.038 | 1 | PROVISIONAL 3.0 — Q30: minimum printed wall for a laminating core | 115.4 | 0.14 | PROVISIONAL: 3.0 mm wall x 1.24 g/cm3. Neither is a quote. | UNKNOWN Q37: infill pattern and density for a core that will be laminated | UNKNOWN Q29: print material the shop will accept under its resin | UNKNOWN Q26: usable build volume, not the catalogue figure | single piece at 264 mm long on any plausible machine | UNKNOWN Q32: maximum unsupported overhang | UNKNOWN Q15: bonding flange width | UNKNOWN Q16: panel gap the shop works to | UNKNOWN Q28: resin exotherm against the print's heat deflection temperature | sill profile and where a bonded flange can land, jack point access after the panel is on | datum only | no |  | PROVISIONAL 15 mm | measured: no approx donor value moves its boundary, and the cabin cut -- the only thing cowl_x and hoop_x reshape -- does not reach it | 03_PRINT/production/P39_ROCKER_END_L_whole.stl
P40 | ROCKER_END_R | R | SIDE | 8 | +Y | printed master -> composite | PROCEED | quote this now | 153.8 | 292.7 | 202.5 | 0.038 | 1 | PROVISIONAL 3.0 — Q30: minimum printed wall for a laminating core | 115.4 | 0.14 | PROVISIONAL: 3.0 mm wall x 1.24 g/cm3. Neither is a quote. | UNKNOWN Q37: infill pattern and density for a core that will be laminated | UNKNOWN Q29: print material the shop will accept under its resin | UNKNOWN Q26: usable build volume, not the catalogue figure | single piece at 264 mm long on any plausible machine | UNKNOWN Q32: maximum unsupported overhang | UNKNOWN Q15: bonding flange width | UNKNOWN Q16: panel gap the shop works to | UNKNOWN Q28: resin exotherm against the print's heat deflection temperature | sill profile and where a bonded flange can land, jack point access after the panel is on | datum only | no |  | PROVISIONAL 15 mm | measured: no approx donor value moves its boundary, and the cabin cut -- the only thing cowl_x and hoop_x reshape -- does not reach it | 03_PRINT/production/P40_ROCKER_END_R_whole.stl
P67 | EYE_BEZEL_OUT_L | L | LIGHTS | 25 | +X | direct print, ASA | PROCEED | quote this now | 251.2 | 142.0 | 92.4 | 0.038 | 1 | PROVISIONAL 3.0 — Q30: minimum printed wall for a laminating core | 115.3 | 0.14 | PROVISIONAL: 3.0 mm wall x 1.24 g/cm3. Neither is a quote. | UNKNOWN Q37: infill pattern and density for a core that will be laminated | UNKNOWN Q29: print material the shop will accept under its resin | UNKNOWN Q26: usable build volume, not the catalogue figure | single piece | UNKNOWN Q32: maximum unsupported overhang | UNKNOWN Q15: bonding flange width | UNKNOWN Q16: panel gap the shop works to | UNKNOWN Q28: resin exotherm against the print's heat deflection temperature | the front structure the housing bolts to, beam aim check on the real car | datum only |  |  | PROVISIONAL 15 mm | only our own data and published donor values reach it | 03_PRINT/production/P67_EYE_BEZEL_OUT_L_whole.stl
P68 | EYE_BEZEL_OUT_R | R | LIGHTS | 25 | +X | direct print, ASA | PROCEED | quote this now | 251.5 | 142.0 | 92.4 | 0.039 | 1 | PROVISIONAL 3.0 — Q30: minimum printed wall for a laminating core | 115.8 | 0.14 | PROVISIONAL: 3.0 mm wall x 1.24 g/cm3. Neither is a quote. | UNKNOWN Q37: infill pattern and density for a core that will be laminated | UNKNOWN Q29: print material the shop will accept under its resin | UNKNOWN Q26: usable build volume, not the catalogue figure | single piece | UNKNOWN Q32: maximum unsupported overhang | UNKNOWN Q15: bonding flange width | UNKNOWN Q16: panel gap the shop works to | UNKNOWN Q28: resin exotherm against the print's heat deflection temperature | the front structure the housing bolts to, beam aim check on the real car | datum only |  |  | PROVISIONAL 15 mm | only our own data and published donor values reach it | 03_PRINT/production/P68_EYE_BEZEL_OUT_R_whole.stl
P01 | FRONT_FASCIA | - | FRONT | 3 | +X | printed master -> composite | CONDITIONAL | do not quote yet: docs/13 supplier answers only | 295.0 | 1659.2 | 483.0 | 0.726 | 1 | PROVISIONAL 3.0 — Q30: minimum printed wall for a laminating core | 2177.5 | 2.7 | PROVISIONAL: 3.0 mm wall x 1.24 g/cm3. Neither is a quote. | UNKNOWN Q37: infill pattern and density for a core that will be laminated | UNKNOWN Q29: print material the shop will accept under its resin | UNKNOWN Q26: usable build volume, not the catalogue figure | splits at the centreline and behind the light blade | UNKNOWN Q32: maximum unsupported overhang | UNKNOWN Q15: bonding flange width | UNKNOWN Q16: panel gap the shop works to | UNKNOWN Q28: resin exotherm against the print's heat deflection temperature | crash beam position and its brackets — the STATEV nose sits 57 mm behind the OEM bumper face, bumper and fender mounting points, radiator position and the space in front of it | boundary position only | no |  | PROVISIONAL 15 mm | front crash structure: the impact absorbers and the bumper beam sit here (P1, Group 5 p. 5-11); how deep this panel's openings may go waits on the beam's real place | 03_PRINT/production/P01_FRONT_FASCIA_whole.stl
P02 | HOOD | - | FRONT | 5 | -Z | printed master -> composite | CONDITIONAL | do not quote yet: docs/13 supplier answers only | 1075.0 | 760.0 | 287.5 | 0.861 | 1 | PROVISIONAL 3.0 — Q30: minimum printed wall for a laminating core | 2583.2 | 3.2 | PROVISIONAL: 3.0 mm wall x 1.24 g/cm3. Neither is a quote. | UNKNOWN Q37: infill pattern and density for a core that will be laminated | UNKNOWN Q29: print material the shop will accept under its resin | UNKNOWN Q26: usable build volume, not the catalogue figure | splits across, behind the vents | UNKNOWN Q32: maximum unsupported overhang | UNKNOWN Q15: bonding flange width | UNKNOWN Q16: panel gap the shop works to | UNKNOWN Q28: resin exotherm against the print's heat deflection temperature | hinge positions and swing arc, frunk aperture and its flange, washer bottle / latch | boundary position only | yes | cowl_x | PROVISIONAL 15 mm, and measured insufficient where BOUNDED_BY is set: the seam travels 15-30 mm with the estimate | measured: boundary moves with cowl_x | none yet
P03 | FRONT_FENDER_L | L | FRONT | 5 | -Y | printed master -> composite | CONDITIONAL | do not quote yet: docs/13 supplier answers only | 1095.0 | 812.0 | 812.2 | 0.863 | 1 | PROVISIONAL 3.0 — Q30: minimum printed wall for a laminating core | 2589.8 | 3.21 | PROVISIONAL: 3.0 mm wall x 1.24 g/cm3. Neither is a quote. | UNKNOWN Q37: infill pattern and density for a core that will be laminated | UNKNOWN Q29: print material the shop will accept under its resin | UNKNOWN Q26: usable build volume, not the catalogue figure | splits at the arch crown | UNKNOWN Q32: maximum unsupported overhang | UNKNOWN Q15: bonding flange width | UNKNOWN Q16: panel gap the shop works to | UNKNOWN Q28: resin exotherm against the print's heat deflection temperature | fender mounting points, wheelhouse liner and its clearance, steering lock envelope — the kingpin axis is unknown, so the swept volume is a worst case | boundary position only | yes | cowl_x;door_front_x | PROVISIONAL 15 mm, and measured insufficient where BOUNDED_BY is set: the seam travels 15-30 mm with the estimate | measured: boundary moves with cowl_x, door_front_x | none yet
P04 | FRONT_FENDER_R | R | FRONT | 5 | +Y | printed master -> composite | CONDITIONAL | do not quote yet: docs/13 supplier answers only | 1095.0 | 812.0 | 812.2 | 0.863 | 1 | PROVISIONAL 3.0 — Q30: minimum printed wall for a laminating core | 2589.8 | 3.21 | PROVISIONAL: 3.0 mm wall x 1.24 g/cm3. Neither is a quote. | UNKNOWN Q37: infill pattern and density for a core that will be laminated | UNKNOWN Q29: print material the shop will accept under its resin | UNKNOWN Q26: usable build volume, not the catalogue figure | splits at the arch crown | UNKNOWN Q32: maximum unsupported overhang | UNKNOWN Q15: bonding flange width | UNKNOWN Q16: panel gap the shop works to | UNKNOWN Q28: resin exotherm against the print's heat deflection temperature | fender mounting points, wheelhouse liner and its clearance, steering lock envelope — the kingpin axis is unknown, so the swept volume is a worst case | boundary position only | yes | cowl_x;door_front_x | PROVISIONAL 15 mm, and measured insufficient where BOUNDED_BY is set: the seam travels 15-30 mm with the estimate | measured: boundary moves with cowl_x, door_front_x | none yet
P21 | REAR_FASCIA | - | REAR | 19 | -X | printed master -> composite | CONDITIONAL | do not quote yet: docs/13 supplier answers only | 420.0 | 1767.1 | 587.2 | 1.207 | 1 | PROVISIONAL 3.0 — Q30: minimum printed wall for a laminating core | 3620.2 | 4.49 | PROVISIONAL: 3.0 mm wall x 1.24 g/cm3. Neither is a quote. | UNKNOWN Q37: infill pattern and density for a core that will be laminated | UNKNOWN Q29: print material the shop will accept under its resin | UNKNOWN Q26: usable build volume, not the catalogue figure | splits at the centreline and outboard of the bar | UNKNOWN Q32: maximum unsupported overhang | UNKNOWN Q15: bonding flange width | UNKNOWN Q16: panel gap the shop works to | UNKNOWN Q28: resin exotherm against the print's heat deflection temperature | rear bumper mounting points and crash structure, exhaust hanger positions | boundary position only | no |  | PROVISIONAL 15 mm | rear crash structure: the rear impact absorbers and beam sit here (P20, Group 5 p. 5-13) at a height nobody has measured; this panel's openings reach into that span | 03_PRINT/production/P21_REAR_FASCIA_whole.stl
P22 | DIFFUSER | - | REAR | 22 | -X | printed master -> composite | CONDITIONAL | do not quote yet: docs/13 supplier answers only | 553.3 | 1779.6 | 375.2 | 1.274 | 1 | PROVISIONAL 3.0 — Q30: minimum printed wall for a laminating core | 3821.9 | 4.74 | PROVISIONAL: 3.0 mm wall x 1.24 g/cm3. Neither is a quote. | UNKNOWN Q37: infill pattern and density for a core that will be laminated | UNKNOWN Q29: print material the shop will accept under its resin | UNKNOWN Q26: usable build volume, not the catalogue figure | splits between fin roots | UNKNOWN Q32: maximum unsupported overhang | UNKNOWN Q15: bonding flange width | UNKNOWN Q16: panel gap the shop works to | UNKNOWN Q28: resin exotherm against the print's heat deflection temperature | underbody and rear subframe, exhaust routing and silencer position, how low a fin can go before it is the first thing to ground out | boundary position only | no |  | PROVISIONAL 15 mm | rear crash structure: the rear impact absorbers and beam sit here (P20, Group 5 p. 5-13) at a height nobody has measured; this panel's openings reach into that span | 03_PRINT/production/P22_DIFFUSER_whole.stl
P26 | TAIL_HOUSING_L | L | LIGHTS | 26 | -X | direct print, ASA | CONDITIONAL | do not quote yet: docs/13 supplier answers only | 184.5 | 731.0 | 60.0 | 0.312 | 1 | PROVISIONAL 3.0 — Q30: minimum printed wall for a laminating core | 936.7 | 1.16 | PROVISIONAL: 3.0 mm wall x 1.24 g/cm3. Neither is a quote. | UNKNOWN Q37: infill pattern and density for a core that will be laminated | UNKNOWN Q29: print material the shop will accept under its resin | UNKNOWN Q26: usable build volume, not the catalogue figure | single piece | UNKNOWN Q32: maximum unsupported overhang | UNKNOWN Q15: bonding flange width | UNKNOWN Q16: panel gap the shop works to | UNKNOWN Q28: resin exotherm against the print's heat deflection temperature | the rear panel it mounts into — comes with REAR_FASCIA | boundary position only |  |  | PROVISIONAL 15 mm | rear crash structure: the rear impact absorbers and beam sit here (P20, Group 5 p. 5-13) at a height nobody has measured; this panel's openings reach into that span | 03_PRINT/production/P26_TAIL_HOUSING_L_whole.stl
P27 | TAIL_HOUSING_R | R | LIGHTS | 26 | -X | direct print, ASA | CONDITIONAL | do not quote yet: docs/13 supplier answers only | 184.5 | 731.0 | 60.0 | 0.313 | 1 | PROVISIONAL 3.0 — Q30: minimum printed wall for a laminating core | 937.6 | 1.16 | PROVISIONAL: 3.0 mm wall x 1.24 g/cm3. Neither is a quote. | UNKNOWN Q37: infill pattern and density for a core that will be laminated | UNKNOWN Q29: print material the shop will accept under its resin | UNKNOWN Q26: usable build volume, not the catalogue figure | single piece | UNKNOWN Q32: maximum unsupported overhang | UNKNOWN Q15: bonding flange width | UNKNOWN Q16: panel gap the shop works to | UNKNOWN Q28: resin exotherm against the print's heat deflection temperature | the rear panel it mounts into — comes with REAR_FASCIA | boundary position only |  |  | PROVISIONAL 15 mm | rear crash structure: the rear impact absorbers and beam sit here (P20, Group 5 p. 5-13) at a height nobody has measured; this panel's openings reach into that span | 03_PRINT/production/P27_TAIL_HOUSING_R_whole.stl
P28 | FRONT_SPLITTER_L | L | FRONT | 4 | +Z | printed master -> composite | CONDITIONAL | do not quote yet: docs/13 supplier answers only | 295.0 | 787.4 | 74.0 | 0.045 | 1 | PROVISIONAL 3.0 — Q30: minimum printed wall for a laminating core | 136.0 | 0.17 | PROVISIONAL: 3.0 mm wall x 1.24 g/cm3. Neither is a quote. | UNKNOWN Q37: infill pattern and density for a core that will be laminated | UNKNOWN Q29: print material the shop will accept under its resin | UNKNOWN Q26: usable build volume, not the catalogue figure | no centreline split needed: the nose mouth already ends it at the centre | UNKNOWN Q32: maximum unsupported overhang | UNKNOWN Q15: bonding flange width | UNKNOWN Q16: panel gap the shop works to | UNKNOWN Q28: resin exotherm against the print's heat deflection temperature | crash beam position and its brackets — the STATEV nose sits 57 mm behind the OEM bumper face, bumper and fender mounting points, radiator position and the space in front of it | boundary position only | no |  | PROVISIONAL 15 mm | front crash structure: the impact absorbers and the bumper beam sit here (P1, Group 5 p. 5-11); how deep this panel's openings may go waits on the beam's real place | 03_PRINT/production/P28_FRONT_SPLITTER_L_whole.stl
P41 | FRONT_SPLITTER_R | R | FRONT | 4 | +Z | printed master -> composite | CONDITIONAL | do not quote yet: docs/13 supplier answers only | 295.0 | 787.4 | 74.0 | 0.045 | 1 | PROVISIONAL 3.0 — Q30: minimum printed wall for a laminating core | 136.0 | 0.17 | PROVISIONAL: 3.0 mm wall x 1.24 g/cm3. Neither is a quote. | UNKNOWN Q37: infill pattern and density for a core that will be laminated | UNKNOWN Q29: print material the shop will accept under its resin | UNKNOWN Q26: usable build volume, not the catalogue figure | no centreline split needed: the nose mouth already ends it at the centre | UNKNOWN Q32: maximum unsupported overhang | UNKNOWN Q15: bonding flange width | UNKNOWN Q16: panel gap the shop works to | UNKNOWN Q28: resin exotherm against the print's heat deflection temperature | crash beam position and its brackets — the STATEV nose sits 57 mm behind the OEM bumper face, bumper and fender mounting points, radiator position and the space in front of it | boundary position only | no |  | PROVISIONAL 15 mm | front crash structure: the impact absorbers and the bumper beam sit here (P1, Group 5 p. 5-11); how deep this panel's openings may go waits on the beam's real place | 03_PRINT/production/P41_FRONT_SPLITTER_R_whole.stl
P43 | FRONT_MASK | - | FRONT | 4 | +X | direct print | CONDITIONAL | do not quote yet: docs/13 supplier answers only | 22.0 | 760.0 | 210.0 | 0.301 | 1 | PROVISIONAL 3.0 — Q30: minimum printed wall for a laminating core | 902.2 | 1.12 | PROVISIONAL: 3.0 mm wall x 1.24 g/cm3. Neither is a quote. | UNKNOWN Q37: infill pattern and density for a core that will be laminated | UNKNOWN Q29: print material the shop will accept under its resin | UNKNOWN Q26: usable build volume, not the catalogue figure | single piece | UNKNOWN Q32: maximum unsupported overhang | UNKNOWN Q15: bonding flange width | UNKNOWN Q16: panel gap the shop works to | UNKNOWN Q28: resin exotherm against the print's heat deflection temperature | crash beam position and its brackets — the STATEV nose sits 57 mm behind the OEM bumper face, bumper and fender mounting points, radiator position and the space in front of it | boundary position only |  |  | PROVISIONAL 15 mm | front crash structure: the impact absorbers and the bumper beam sit here (P1, Group 5 p. 5-11); how deep this panel's openings may go waits on the beam's real place | 03_PRINT/production/P43_FRONT_MASK_whole.stl
P44 | DIFFUSER_FIN_INNER_L | L | REAR | 23 | -Z | direct print | CONDITIONAL | do not quote yet: docs/13 supplier answers only | 400.0 | 16.0 | 206.0 | 0.098 | 1 | PROVISIONAL 3.0 — Q30: minimum printed wall for a laminating core | 295.0 | 0.37 | PROVISIONAL: 3.0 mm wall x 1.24 g/cm3. Neither is a quote. | UNKNOWN Q37: infill pattern and density for a core that will be laminated | UNKNOWN Q29: print material the shop will accept under its resin | UNKNOWN Q26: usable build volume, not the catalogue figure | single piece | UNKNOWN Q32: maximum unsupported overhang | UNKNOWN Q15: bonding flange width | UNKNOWN Q16: panel gap the shop works to | UNKNOWN Q28: resin exotherm against the print's heat deflection temperature | underbody and rear subframe, exhaust routing and silencer position, how low a fin can go before it is the first thing to ground out | boundary position only |  |  | PROVISIONAL 15 mm | rear crash structure: the rear impact absorbers and beam sit here (P20, Group 5 p. 5-13) at a height nobody has measured; this panel's openings reach into that span | 03_PRINT/production/P44_DIFFUSER_FIN_INNER_L_whole.stl
P45 | DIFFUSER_FIN_INNER_R | R | REAR | 23 | -Z | direct print | CONDITIONAL | do not quote yet: docs/13 supplier answers only | 400.0 | 16.0 | 206.0 | 0.098 | 1 | PROVISIONAL 3.0 — Q30: minimum printed wall for a laminating core | 295.0 | 0.37 | PROVISIONAL: 3.0 mm wall x 1.24 g/cm3. Neither is a quote. | UNKNOWN Q37: infill pattern and density for a core that will be laminated | UNKNOWN Q29: print material the shop will accept under its resin | UNKNOWN Q26: usable build volume, not the catalogue figure | single piece | UNKNOWN Q32: maximum unsupported overhang | UNKNOWN Q15: bonding flange width | UNKNOWN Q16: panel gap the shop works to | UNKNOWN Q28: resin exotherm against the print's heat deflection temperature | underbody and rear subframe, exhaust routing and silencer position, how low a fin can go before it is the first thing to ground out | boundary position only |  |  | PROVISIONAL 15 mm | rear crash structure: the rear impact absorbers and beam sit here (P20, Group 5 p. 5-13) at a height nobody has measured; this panel's openings reach into that span | 03_PRINT/production/P45_DIFFUSER_FIN_INNER_R_whole.stl
P46 | DIFFUSER_FIN_OUTER_L | L | REAR | 23 | -Z | direct print | CONDITIONAL | do not quote yet: docs/13 supplier answers only | 300.0 | 16.0 | 171.6 | 0.065 | 1 | PROVISIONAL 3.0 — Q30: minimum printed wall for a laminating core | 194.0 | 0.24 | PROVISIONAL: 3.0 mm wall x 1.24 g/cm3. Neither is a quote. | UNKNOWN Q37: infill pattern and density for a core that will be laminated | UNKNOWN Q29: print material the shop will accept under its resin | UNKNOWN Q26: usable build volume, not the catalogue figure | single piece | UNKNOWN Q32: maximum unsupported overhang | UNKNOWN Q15: bonding flange width | UNKNOWN Q16: panel gap the shop works to | UNKNOWN Q28: resin exotherm against the print's heat deflection temperature | underbody and rear subframe, exhaust routing and silencer position, how low a fin can go before it is the first thing to ground out | boundary position only |  |  | PROVISIONAL 15 mm | rear crash structure: the rear impact absorbers and beam sit here (P20, Group 5 p. 5-13) at a height nobody has measured; this panel's openings reach into that span | 03_PRINT/production/P46_DIFFUSER_FIN_OUTER_L_whole.stl
P47 | DIFFUSER_FIN_OUTER_R | R | REAR | 23 | -Z | direct print | CONDITIONAL | do not quote yet: docs/13 supplier answers only | 300.0 | 16.0 | 171.6 | 0.065 | 1 | PROVISIONAL 3.0 — Q30: minimum printed wall for a laminating core | 194.0 | 0.24 | PROVISIONAL: 3.0 mm wall x 1.24 g/cm3. Neither is a quote. | UNKNOWN Q37: infill pattern and density for a core that will be laminated | UNKNOWN Q29: print material the shop will accept under its resin | UNKNOWN Q26: usable build volume, not the catalogue figure | single piece | UNKNOWN Q32: maximum unsupported overhang | UNKNOWN Q15: bonding flange width | UNKNOWN Q16: panel gap the shop works to | UNKNOWN Q28: resin exotherm against the print's heat deflection temperature | underbody and rear subframe, exhaust routing and silencer position, how low a fin can go before it is the first thing to ground out | boundary position only |  |  | PROVISIONAL 15 mm | rear crash structure: the rear impact absorbers and beam sit here (P20, Group 5 p. 5-13) at a height nobody has measured; this panel's openings reach into that span | 03_PRINT/production/P47_DIFFUSER_FIN_OUTER_R_whole.stl
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

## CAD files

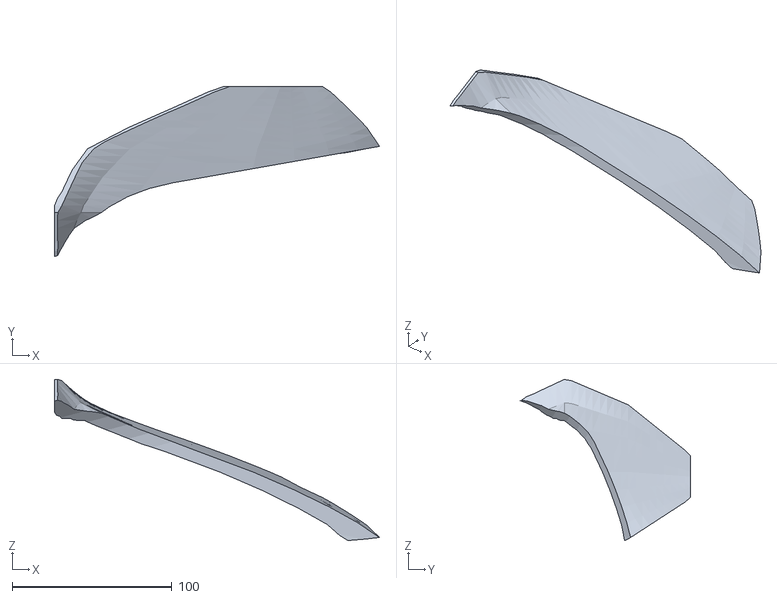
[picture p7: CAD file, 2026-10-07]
03_PRINT/production/P66_EYE_BEZEL_IN_R_whole.stl
203.4 x 106.4 x 100.8

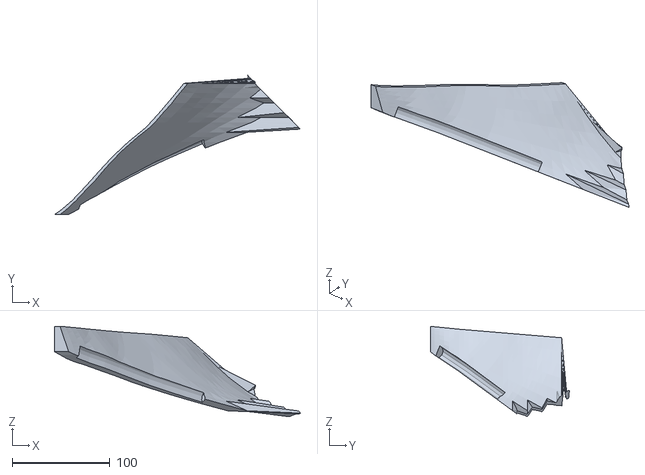
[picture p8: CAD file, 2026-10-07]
03_PRINT/production/P68_EYE_BEZEL_OUT_R_whole.stl
251.2 x 142.0 x 92.4

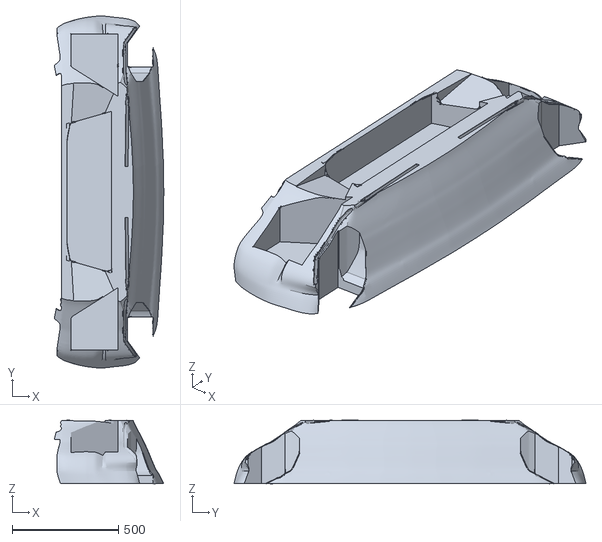
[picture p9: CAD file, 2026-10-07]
03_PRINT/production/P01_FRONT_FASCIA_whole.stl
516.1 x 1658.5 x 300.7

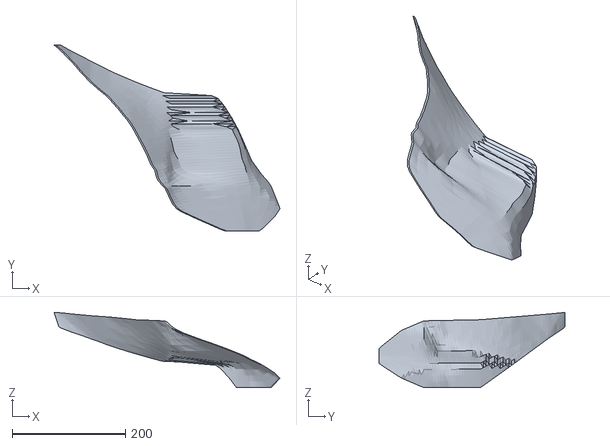
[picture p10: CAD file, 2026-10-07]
03_PRINT/production/P69_EYE_COVER_L_whole.stl
399.2 x 328.0 x 133.0

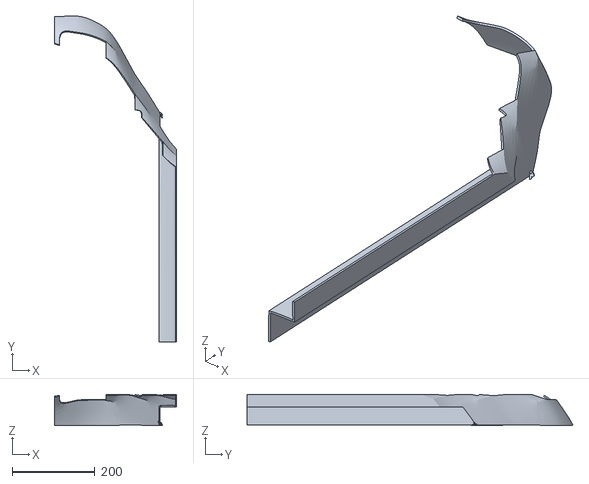
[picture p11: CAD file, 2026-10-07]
03_PRINT/production/P41_FRONT_SPLITTER_R_whole.stl
295.2 x 787.2 x 75.5

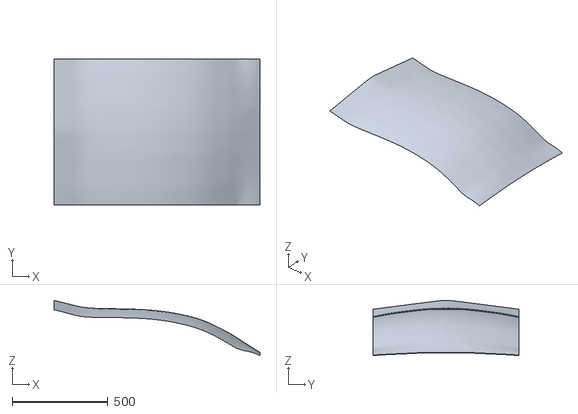
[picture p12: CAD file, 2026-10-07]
03_PRINT/shape_only/P02_HOOD_whole.stl
1075.7 x 760.0 x 287.9

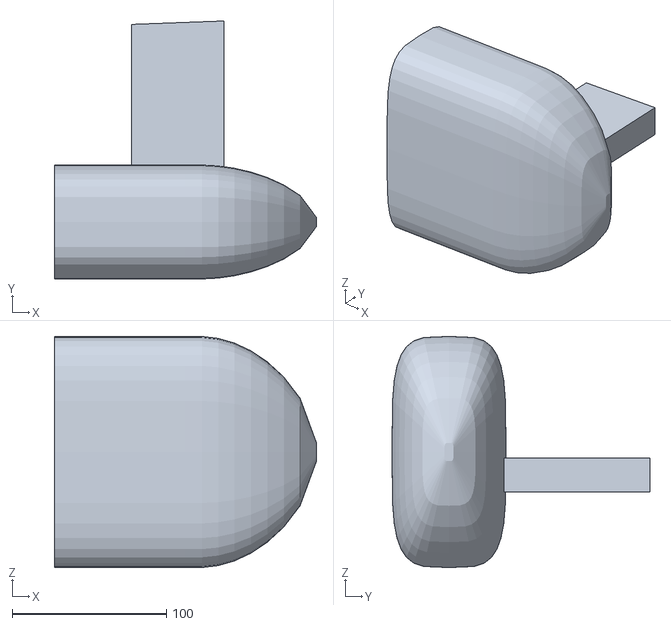
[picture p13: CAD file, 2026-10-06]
03_PRINT/shape_only/P37_MIRROR_CAP_L_whole.stl
170.0 x 167.4 x 150.0

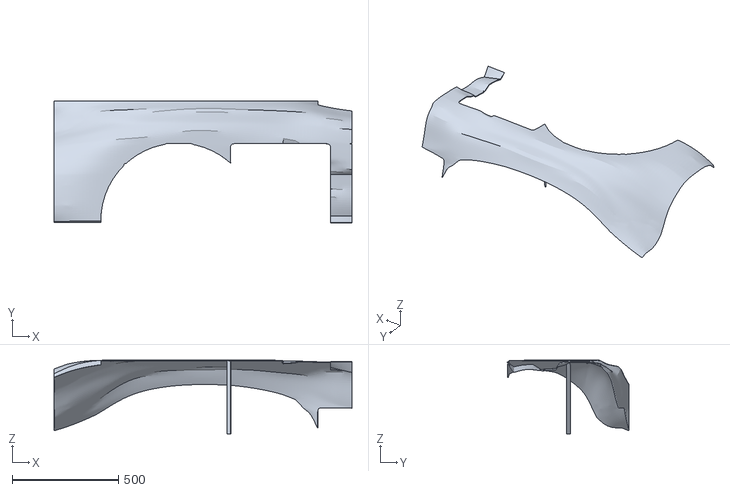
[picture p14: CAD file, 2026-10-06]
03_PRINT/shape_only/P16_REAR_HAUNCH_R_whole.stl
1400.5 x 572.6 x 346.0

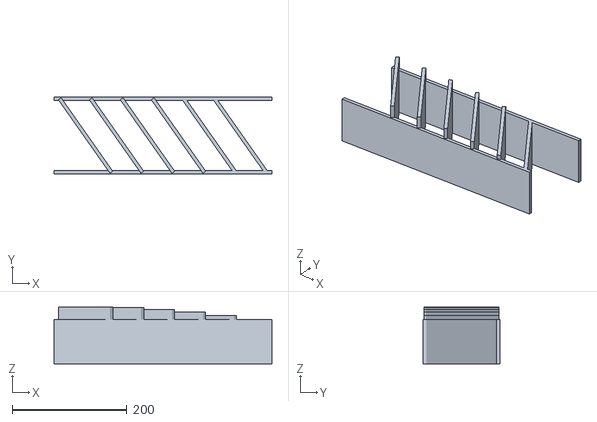
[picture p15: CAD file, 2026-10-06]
03_PRINT/production/P05_FENDER_CHANNEL_L_whole.stl
380.0 x 134.0 x 98.6

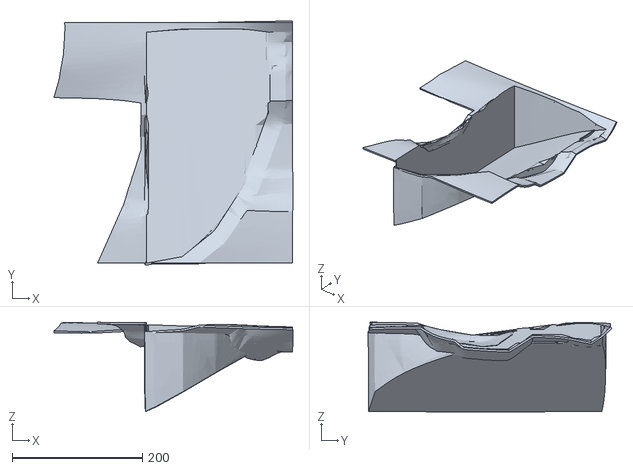
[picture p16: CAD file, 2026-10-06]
03_PRINT/shape_only/P11_SIDE_INTAKE_L_whole.stl
367.3 x 374.7 x 137.6

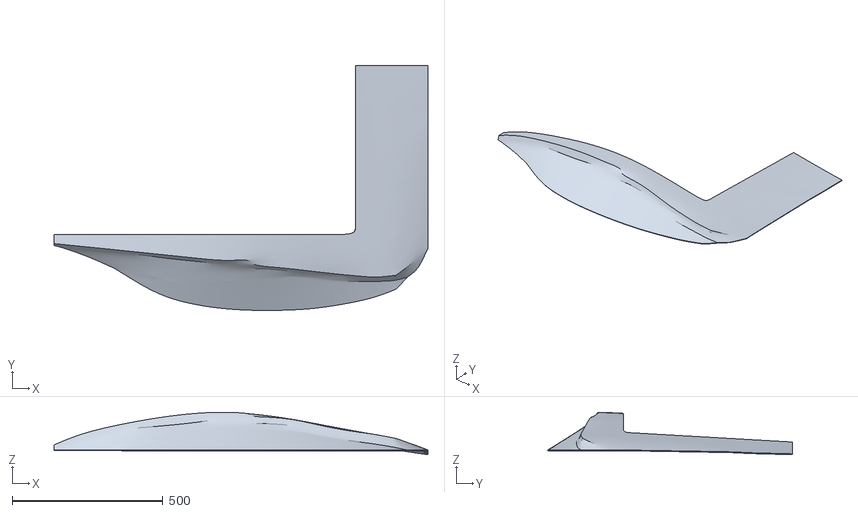
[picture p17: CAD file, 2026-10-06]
03_PRINT/shape_only/P42_REAR_DECK_R_whole.stl
1240.0 x 812.1 x 140.6

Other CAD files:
03_PRINT/production/P28_FRONT_SPLITTER_L_whole.stl
03_PRINT/production/P70_EYE_COVER_R_whole.stl
03_PRINT/shape_only/P38_MIRROR_CAP_R_whole.stl
03_PRINT/production/P65_EYE_BEZEL_IN_L_whole.stl
03_PRINT/production/P67_EYE_BEZEL_OUT_L_whole.stl
03_PRINT/production/P06_FENDER_CHANNEL_R_whole.stl
03_PRINT/shape_only/P12_SIDE_INTAKE_R_whole.stl
02_DESIGN/exterior/EXPERIMENT_undercut_xb2850_UNAPPROVED.blend
02_DESIGN/exterior/EXPERIMENT_undercut_xb2950_UNAPPROVED.blend
02_DESIGN/exterior/EXPERIMENT_undercut_xb3050_UNAPPROVED.blend
02_DESIGN/exterior/STATEV_001_v001.blend
02_DESIGN/exterior/STATEV_001_v002.blend
02_DESIGN/exterior/STATEV_001_v003.blend
02_DESIGN/exterior/STATEV_001_v004.blend
02_DESIGN/exterior/STATEV_001_v005.blend
02_DESIGN/exterior/STATEV_001_v006.blend
02_DESIGN/exterior/STATEV_001_v007.blend
02_DESIGN/exterior/STATEV_001_v008.blend
02_DESIGN/exterior/STATEV_001_v009.blend
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

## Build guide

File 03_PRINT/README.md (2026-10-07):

# STATEV 001 — print files: what is in this folder and what to do with it

*Generated by `print_qc.py` from the last production run. Do not edit by hand; re-run the pipeline instead.*

## Two tiers, two folders

**WHOLE PANELS.** One file per part, decided by the owner on 2026-09-26. The bed below is a large-format REFERENCE (Modix BIG-180X class), used only to flag which parts would not fit it; nothing is cut to it. Tell us your real build volume (docs/13 Q26) and the same chain cuts every part to it.

| folder | parts | files | one piece | fits bed | what it is |
|---|---|---|---|---|---|
| `production/` | 39 | 41 | 41 | 41 | cores whose outer shape is final; mounting interface still to come from the donor scan |
| `shape_only/` | 17 | 19 | 19 | 19 | shape masters for fitting — **not** parts to bond; the inner face or the trim edge depends on the car |

Every file is one printable solid, laid on its flattest face, sitting on Z = 0, in **millimetres**. Print it as it comes. `placement.json` in each folder carries the matrix that puts each file back on the car; `04_ENGINEERING/reports/print_schedule.csv` carries the same as degrees and millimetres.

## What the files assume — every one is provisional until the shop answers docs/13

| assumption | value | replaced by |
|---|---|---|
| build volume | 1800 × 600 × 1800 mm, 10 mm margin | Q26 — **reference only in whole-panel mode; a smaller bed means cutting** |
| wall | 3.0 mm | Q30 |
| material density | 1.24 g/cm³ (generic PLA, unmeasured) | Q37 |
| bonding flange | 30 mm + 1 mm bond line | Q15 |
| panel gap | 4 mm | Q14 |
| joint tab | 20 mm past each cut, dropped inward by wall + bond | fit test |
| orientation | smallest dimension vertical | Q32 / Q33 |

Estimated core mass across both tiers at these assumptions: **~78.8 kg**.

## Quality of the files, as a slicer sees them

`print_qc.py` reads every file back: closed, manifold, consistently wound, positive volume. Last run: **60 of 60 clean**, 0 with a defect.

## Known problems, stated rather than hidden

- **997 cm² of skin is in no file**: seam slivers and lone faces the region rule handed to a panel without connecting them to it, dropped and counted per file in `DROPPED_MM2`. The laminate bridges these; none is a part.
- The files are the **core** only. Laminate, filler and paint go on top and none of their thicknesses exist as data yet.
- Orientation is *lay flattest, class-A face up* — never chosen against an overhang limit (Q32). `04_ENGINEERING/reports/overhang.csv` says, per file, how much area hangs past 45° and 60° as laid and turned over, so the shop's limit turns into a count rather than a question.
- Nothing here touches the donor car. Every mounting point, hinge, hole and flange that lands on the Porsche is deliberately absent until the car is scanned.

## Before printing all of it: print ONE panel

`04_ENGINEERING/reports/fit_test_P39.txt` names the panel (P39 ROCKER_END_L), the assumptions one print tests, six landmarks to measure with a caliper at four stages, and what a change at each stage means. That test is a hard rule of this project, not a suggestion.

## Shape-only tier: what each part is still missing

- **P03** — outer form ours; the inner face is the donor's fender line. Carries a 30 mm TRIM ALLOWANCE past the door shut line (overlaps P09 by 30 mm): the line moves with door_front_x by +-15..30 mm and the scan says where to cut.
- **P04** — mirror of P03, same note
- **P09** — outer form ours; the inner face is currently just the outer offset by the wall and is NOT the OEM door skin. Carries a 30 mm TRIM ALLOWANCE past both shut lines (overlaps P03 and P15). Fit and bond surface come from the scan.
- **P10** — mirror of P09, same note
- **P15** — outer form ours; overlay on the welded quarter, inner face provisional as P09. Carries a 30 mm TRIM ALLOWANCE past the rear shut line (overlaps P09).
- **P16** — mirror of P15, same note
- **P11** — outer form ours (the intake surround, spec X 1700..2170 above the rocker, round the v069 scoop and the mouth); the real opening behind it and the duct route are the donor's. Fit and bond surface come from the scan, as for P15.
- **P12** — mirror of P11, same note
- **P63** — SHAPE ONLY in the strongest sense: the hump behind the left seat, a 4 mm shell on the deck. It stands where the 986 stows its top; whether it lifts with the lid as on the Boxster Spyder is scan S2's answer. Print it to look at the car, not to bond.
- **P64** — mirror of P63, same note
- **P37** — outer form ours (a cap over a bought E-marked mirror, head spec X 630..800, |Y| 730..880); the cap's inner face follows the chosen mirror and the stalk's door mount comes from the scan. Print it to judge the car, not to fit.
- **P38** — mirror of P37, same note
- **P19** — SHAPE ONLY in the strongest sense: the deck from the hoop plane to the fascia, around the engine cover. Its HEIGHT is the roof question (docs/14, DECK_SPINE BLOCKED): scan S2 decides whether it stays, moves with the clamshell or drops. Print to look, not to bond.
- **P42** — mirror of P19, same note
- **P20** — SHAPE ONLY in the strongest sense: the engine cover with the louvre aperture, spec X 2000..3000, |Y| < 560. Height as P19 (roof); the hinge, the latch and the real engine lid opening are the donor's. Print to look, not to bond.
- **P33** — SHAPE ONLY: the louvre crate standing in P20's aperture -- seven transverse slats on seven longitudinal ribs, tops 8 mm under the cover's skin. Goes with P20.
- **P02** — outer form ours between the fender crests (|Y| < 380). Rear edge: the file ends at spec X ~385, 35 mm short of the donor cowl (420) -- no allowance can be carried across the cabin cut, so the real rear edge, the hinges and the frunk aperture come from the scan.

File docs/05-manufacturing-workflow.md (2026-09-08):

# 05 — Manufacturing workflow

## Верига (one-off)

скан/клетка → Blender surfacing → дебелина/фланци/разрязване → STL/3MF →
външен печат (PLA/PETG мастер) → пробен монтаж на колата → 2–3 слоя стъклопласт
директно върху принта (принтът е ядро) → кит → шкурка → грунд → боя (бояджия)
→ монтаж.

**Без калъпи** за one-off. Калъпи (мастер → калъп → композит) само ако се
продава кит — тогава повърхността и повторяемостта го оправдават.

## Печат — параметри за мастер

- PLA (евтин, лесен за шкурене) или PETG (по-здрав).
- Дюза 1.0 mm ако принтерът има; 0.4–0.6 mm слой; 3–4 стени; 5–10% gyroid infill.
- Разрязване по build volume на принтера (**питай преди да режеш**).
- Tongue & groove или ключове за подравняване, скрити болтове/heat-set inserts
  при нужда, номер на частта в името на файла.
- Един PDF с експлодиран изглед, ориентация за печат, материал, infill.
- Голям преден калник на 986 (~950–1100 × 350–450 × 500 mm) става на едно
  парче на Modix BIG-180X клас; на по-малък принтер — 2–4 парчета.

## Композит

- Стъклопласт: евтин, лесен за ремонт — за всички големи панели.
- Карбон (истински: плат + епоксид + вакуум) — само за визуални акценти (blades,
  сплитер, дифузьор), ако бюджетът позволи. CF филамент ≠ карбонов панел.
- Хибрид (карбон отгоре + стъклопласт отдолу) — когато е нужен look без пълна
  цена.

## Монтаж

- Броня/калници: OEM точки — болтове, скоби, клипси.
- Маска/решетки: tabs, винтове, heat-set inserts.
- Сплитер/дифузьор: болтове, резбови вложки, метални скоби.
- Овърлей на задните квартери: PU/структурно лепило + механично закрепване по
  ръбовете; flush секция — фланец от изрязана OEM обшивка.
- Декоративен trim: PU лепило.

## Ред на печат / монтаж

1. **Един преден калник** — тест на скана, дизайна, фугите, клирънса на колелото
   при пълен ход и завъртане. Нищо друго не се печата преди корекцията.
2. Преден clamshell (капак, калници, маска).
3. Заден deck + перки + квартери.
4. Задна броня/дифузьор.
5. Врати (outer skin) и прагове.
6. Дребни части: blades, корпуси за светлини, решетки, огледала.

## Тежест

Стъклопластов квартер overlay 2.5–3 mm ≈ 3–4 kg/страна. Композитни капаци и
брони вместо OEM стомана/пластмаса връщат 25–30 kg. Нетно колата олеква.

## Safety

3D печатана термопластика никога не замества crash beam, структурни елементи,
монтажни точки на окачване/седалки/кормилна, без инженерна валидация.

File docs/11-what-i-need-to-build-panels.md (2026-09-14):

# Какво да поискаш от ChatGPT — и какво НЕ

## Не искай размери на панели в милиметри

Три пъти досега числа от този източник влязоха в конфликт с донора:
главините искаха +285 mm следа, фарът стърчеше 215 mm извън каросерията,
страничният отвор не се припокриваше с реалния, кожата на вратата беше
145 mm по-къса от отвора, deck-ът стоеше над седалките.
Всяко от тях се хвана само защото имаме донорски данни, с които да сверим.

Милиметрите на всичко, което пипа донора, идват от колата. Не от текст.

## Искай това — описание на формата, не размери

Копирай следното:

---
За STATEV 001 (Porsche Boxster 986 донор, сменяме само външните панели) ми
дай описание на ФОРМАТА, не размери в милиметри. За всеки панел от списъка
по-долу попълни таблица със следните колони:

| feature | какво е | къде е (в % от дължината и височината на панела) | отвор ли е | функционален ли е | изпъкнало / вдлъбнато / ръб |

Панели:
FRONT_CLAMSHELL, HOOD, FRONT_FENDER, DOOR_SKIN, ROCKER, SIDE_INTAKE,
REAR_HAUNCH, REAR_DECK, ENGINE_COVER, REAR_FASCIA, DIFFUSER,
HEADLIGHT, TAIL_LIGHT, BUTTRESS, REAR_SPOILER

Правила:
- Никакви абсолютни милиметри. Само относителни пропорции и посоки.
- За всеки отвор кажи къде влиза и къде излиза въздухът.
- За всяка характерна линия кажи откъде тръгва и къде свършва, спрямо
  фиксираните точки: предна ос, фуга на вратата, roll hoop, задна ос.
- Ако нещо в рендера не може да съществува върху 986 (стъкло, дъги,
  междуосие, следа), кажи го изрично вместо да го замълчиш.
- Отделно: предложи КЪДЕ да минават фугите между панелите и защо всяка
  от тях е там (достъп, сваляемост, производство, съществуваща фуга).
---

## Какво мога да ползвам директно от отговора

Описанието на формата → влиза в спецификацията като намерение.
Логиката на фугите → влиза в панелната архитектура.
Списъкът с отвори и въздушни пътища → влиза в проверките.

Нищо от него не влиза като размер, докато няма скан.

## Какво ми трябва, за да стигнем до файлове за принтиране

Веригата е фиксирана и всяко звено блокира следващото.

### 1. Донорът — блокира всичко

Няма кола. Всяко число за донора в проекта идва от чертеж с 9 mm на пиксел и
от workshop manual. Толерансът е ±15–30 mm. Панел с фланец не се прави при
±30 mm. Докато няма кола, всичко тук е проектна геометрия.

### 2. Сканът — блокира панелите

От него идва всичко, което не може да дойде отникъде другаде:

| Какво | Защо блокира |
|---|---|
| Външна обшивка с монтираните панели | референция за фугите и преливането |
| Същото със свалени брони и калници | монтажни точки, crash beam, радиатори |
| Двигателен отсек отгоре | докъде може да слезе deck-ът, къде минава каналът |
| Покривът в 4 положения: затворен, полуотворен, отворен, вдигнат clamshell | **риск №1** — deck на Z 960 и рамене на 1090 стоят точно там |
| Интериор със седалка в позиция за 190 cm | сглобяемост |
| Контролни размери с рулетка | проверка на скана |

Списъкът е в `docs/02-hardpoints-986.md` и не се е променил.

### 3. Решения, които са твои и не чакат кола

- **Build volume на принтера.** Определя как се режат панелите. Без него не
  мога да направя split. Питай човека/фермата за X, Y, Z в mm.
- **Скенер.** Revopoint Range 2 / POP 3, €500–900, по бюджета. Купува се
  преди донора, за да има върху какво да се учи.
- **Deck-ът отваря ли се с clamshell-а.** Проверява се на реална кола, но
  решението как искаш да е е твое.

### 4. Какво мога да правя дотогава

- Да държа скелета изравнен с референциите. Това вече работи и е евтино.
- Да направя осевия профил по силуета на ref-08.
- Да построя панелната архитектура и логиката на фугите като намерение.
- Да направя капака на огледалото — целият път от Blender до принтиран
  предмет, върху част, която не зависи от донора. Това е единственото нещо в
  списъка, което може да стигне до реален принт тази седмица.

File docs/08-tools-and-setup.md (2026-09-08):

# 08 — Инструменти и настройка

## Машина

MacBook Pro M1 Pro, 32 GB — достатъчна за Blender, скан обработка, големи STL.

## Софтуер (без абонаменти)

| Инструмент | За какво | Статус |
|---|---|---|
| Blender 5.2 | Всичко surfacing; subdivision modelling върху референции | инсталиран |
| Blender MCP (ahujasid/blender-mcp) | Claude управлява Blender: клетка, импорт/мащаб, измервания, clearance, разрязване, експорт | addon инсталиран, порт 9876, telemetry OFF |
| uv / uvx | Стартира MCP сървъра | инсталиран (brew) |
| Claude Desktop | Чат + Blender MCP за интерактивна работа | конфигурира се |
| Claude Code | Repo, скриптове, git, Blender MCP за скриптовата фаза | следваща стъпка |
| Plasticity (€99–299 еднократно) | NURBS: дебелина, фланци, разрязване — ако Blender стане болезнен | по-късно, при нужда |
| Revo Scan | Скенерът | при покупка на скенера |
| Fusion 360 | Не е нужен за този workflow | — |

## Blender MCP — Claude Desktop

`~/Library/Application Support/Claude/claude_desktop_config.json`:

```json
{
  "mcpServers": {
    "blender": {
      "command": "uvx",
      "args": ["blender-mcp"]
    }
  }
}
```

Ако Claude Desktop не намира uvx (`spawn uvx ENOENT`): `which uvx` в
терминала и сложи пълния път (обикновено `/opt/homebrew/bin/uvx`).
В Blender: N → таб "MCP for Blender" → Connect to MCP server (порт 9876).
Blender трябва да е отворен преди старта на Claude.

## Claude Code — инсталация и закачане към репото

```bash
# инсталация (native, без Node)
curl -fsSL https://claude.ai/install.sh | bash
claude --version
claude doctor

# в папката на репото
cd ~/path/to/vehicle-3d-modeling
claude            # първи старт → /login с claude.ai акаунта

# Blender MCP за Claude Code (Blender отворен, сървърът стартиран)
claude mcp add blender -- uvx blender-mcp
claude mcp list   # blender трябва да е с отметка
```

Claude Code чете `CLAUDE.md` автоматично при всяка сесия. Референтните
картинки в `07_PRESENTATION/references/` се четат с "отвори ref-05" — Claude
Code вижда изображения от файловата система.

Алтернатива без терминал: Claude Desktop → таб Code → отваряш папката на
репото; същото поведение.

## Git конвенции

- Commit при всеки завършен етап (`fender v3 — arch line fixed`).
- `.blend1`/`.blend2` бекъпи, `__pycache__`, временни експорти — в `.gitignore`.
- Големи STL (>50 MB) — Git LFS или извън репото с линк.
- Клетката винаги се регенерира от `01_CAD/scripts/cage_986.py`, никога не се
  редактира ръчно.

## Учебен път в Blender (само това, което трябва)

1. Навигация, модификатори, Subdivision Surface, Mirror, Shrinkwrap (за
   snap към скан/подложка).
2. Reference Images в трите равнини, мащабиране по междуосието.
3. Subdivision modelling на калник върху подложка — търси "Blender car
   modeling tutorial" (CG Fast Track, Blender Guru за основи).
4. Solidify, Boolean, разрязване за печат, експорт STL/3MF.

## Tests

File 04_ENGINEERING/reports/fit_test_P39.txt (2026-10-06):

================================================================================================
FIT TEST — P39 ROCKER_END_L
================================================================================================

  CLAUDE.md hard constraint 6: one panel is printed, laminated and checked BEFORE
  the rest. This is that panel, and this sheet is what the check consists of.

  WHAT ONE PRINT ANSWERS
    - does a 3 mm printed wall survive lamination without distorting
        docs/13 Q30 — the wall is a DESIGN ASSUMPTION, never tested
    - does the section print at the orientation the pipeline chose
        docs/13 Q32/Q33 — orientation is 'lay flattest', not chosen against an overhang limit
    - is the printed part the size the file says
        shrinkage is assumed zero; PLA and PETG are not zero
    - do filler and paint bury this part's character edges
        7 outer edges turn more than 20 degrees, the sharpest 48 -- measured from the file; nobody has seen them under paint
    - does the finished panel still match the design surface
        assembly_check says the FILES do, to a median of 0.00 mm. The PART is a different claim.
    - NOT answered by this panel: whether the tab joint holds two sections in line.
        Whole panels print as one file, so there is no joint; it is tested only if the
        shop's real bed (docs/13 Q26) forces a cut, on the first panel that gets one.

  THE FILES — 1 section(s), print all of them
    file                                               L       W       H  one piece
    P39_ROCKER_END_L_whole.stl                     220.2   294.6   205.4  yes

    Each file is already laid on its flattest face and sitting on Z = 0. Print it as
    it comes; do not re-orient it, because the schedule's placement puts it back on
    the car in that orientation and nothing else records which way up it went.

  THE MEASUREMENTS — a caliper and a steel rule, no scanner
    Six landmarks, each an extreme of the part, so each is a corner or a tip you can
    put a jaw on. Measure every pair at every stage and write the number down.

    landmark          spec X         Y         Z
    front-most        2712.6     628.6     129.8
    rear-most         2932.8     713.9     229.0
    left-most         2779.6     903.8     330.0
    right-most        2866.7     611.1     130.2
    lowest            2712.8     630.5     127.5
    highest           2866.5     889.1     332.9

    DESIGN DISTANCES, in millimetres. These are what the part is checked against.
      front-most     -> rear-most          256.1
      front-most     -> left-most          346.9
      front-most     -> right-most         155.0
      front-most     -> highest            364.4
      rear-most      -> left-most          264.1
      rear-most      -> right-most         157.1
      rear-most      -> lowest             256.2
      rear-most      -> highest            214.2
      left-most      -> right-most         364.9
      left-most      -> lowest             346.7
      left-most      -> highest             88.3
      right-most     -> lowest             155.1
      right-most     -> highest            344.0
      lowest         -> highest            364.3

  WHEN TO MEASURE, and what a change at each stage means
    1. straight off the printer, per section   -> shrinkage, and whether the
       printer built the file it was given
    2. (one file: no sections to bond -- skip)
    3. after laminate, before filler           -> whether the wall distorted under
       the resin's heat and shrinkage
    4. after filler and paint                  -> the finished panel, and whether
       the character lines are still readable

  WHAT PASSING MEANS, and it is a decision, not a measurement
    This project has no tolerance from anybody yet — docs/13 Q13 (composite) and Q29 (print) are unanswered — so
    no number here can be called a limit without inventing one. What the sheet can
    say honestly is the SCALE the rest of the work assumes:
      - the panel gaps are designed at 4 mm, so a joint that moves more than about
        2 mm eats half the gap and will show;
      - the flange is 30 mm with a 1 mm bond line, so a face out of plane by more
        than 1 mm has nothing left to bond into;
      - the whole car is built to a locked width of 1850 mm; a panel 1 % off is
        18 mm, which is four gaps.
    Write the measured numbers down, then decide with the composite shop. The point
    of this panel is to have real numbers in that conversation instead of a plan.

  WHAT THIS TEST CANNOT TELL YOU
    It says nothing about anything that touches the donor — this panel was chosen
    because it does not. Fit to the car is a separate test, after the scan, and it
    is the only one of the two that the scan can change.

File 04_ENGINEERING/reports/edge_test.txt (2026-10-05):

====================================================================================================
EDGE TEST — docs/16's CONTINUITY classes, as dihedral angles on the built mesh
====================================================================================================

  G0 wants 40-110 deg (a break), G1 wants 8-40 (a transition), G2 wants under 9
  (the main surfaces stay soft -- chasing G2 everywhere is what makes CAD soap,
  and a crease where the map says G2 is the same defect inverted).

  line                                         cls    n    mesh   design    lost  verdict
  DOOR_UPPER -> DOOR_CHANNEL (the side lip)    G0    11    67.0     72.4     5.4  ok
  REAR_FASCIA -> DIFFUSER (undercut edge)      G0     4    73.1     63.1   -10.1  ok
  DOOR_UPPER -> ROCKER (sill line)             G1    13    65.5     49.5   -16.0  out of band — RECORDED exception
  REAR_HAUNCH_TOP -> REAR_HAUNCH_SIDE          G1     8    14.5     14.8     0.3  ok
  BUTTRESS -> REAR_DECK (haunch crest)         G1     8    70.0     74.1     4.2  out of band — RECORDED exception
  FRONT_FENDER_TOP -> FRONT_FENDER_SIDE (crest) G1     9    51.9     64.0    12.2  out of band — RECORDED exception

  LINES IN BAND 3 / RECORDED EXCEPTION 3 / DEFECT 0  (of 6 measured)

  DOOR_UPPER -> ROCKER (sill line) — 2026-09-28: the sill is no longer a 34 mm tuck -- the rocker stands out as a BLADE at 918 (statev_master_volumes ROCKER_BLADE) and its top is a ~56 mm shelf over 30 mm of height, so the line is two G0 breaks 30 mm apart, not one G1 transition. Measured at the shelf's lower crease: 65.5 degrees on 13 stations (the finder read 0.9 until its radial filter was made per-face on 2026-09-28 -- the shelf's up-facing face was being thrown away). docs/16 classes DOOR_UPPER -> ROCKER as G1 and the built sill is a G0 shelf: that is the rebuilt side of docs/14 section I, not a defect of the mesh. Older text: sharpened 55 -> 18 -> 10 mm on 2026-09-15/16, measured ~47 against a G1 band this file invented; the OWNER'S CALL on that band still stands for the crest.
  BUTTRESS -> REAR_DECK (haunch crest) — measured for the first time 2026-10-05 (v064). The DESIGN turns 74 degrees here -- the two-point deck edge of 2026-09-15 -- and the mesh showed 46 until the crest was anchored, 70 after. docs/16 classes it G1; ref-09's top view draws it as a crisp crease, and the owner asked for exactly that the same day ("continue with the fender edges"). The third G1 line of docs/16 designed well above 40 -- with the crest and the sill, one question: is docs/16's G1 band the right one for this car's language.
  FRONT_FENDER_TOP -> FRONT_FENDER_SIDE (crest) — the DESIGN turns 55.5 degrees here and always has; the mesh was rendering 44.2 until the crest was anchored on 2026-09-21, and 38.6 before that. So this is not a line that got sharper, it is a line that became visible. docs/16 classes it G1 and this file's G1 band tops out at 40 -- a number this file invented, not one docs/16 gives. OWNER'S CALL, and it is the SAME call as the rocker below: two of docs/16's G1 lines are designed at about 50 degrees, so either the band is too tight for a car with this language, or both lines are harder than the spec intends.

  ------------------------------------------------------------------------------------------------
  COVERAGE — every transition in CONTINUITY, and what evidence exists for it
  ------------------------------------------------------------------------------------------------

  transition                             cls             crease  break made by                               
  BUTTRESS -> REAR_DECK                  G1          70.0 deg !  nothing                                     
  DOOR_CHANNEL -> SIDE_INTAKE_MOUTH      G1     no line defined  opening INTAKE_BLADE_L                      
  DOOR_UPPER -> DOOR_CHANNEL             G0         67.0 deg ok  nothing                                     
  DOOR_UPPER -> REAR_HAUNCH_TOP          G2     no line defined  seam DOOR_SHUT_REAR (0.00 mm off skin)      
  DOOR_UPPER -> ROCKER                   G1          65.5 deg !  seam ROCKER_to_UPPER_BODY (0.00 mm off skin)
  ENGINE_COVER -> REAR_FASCIA            G1     no line defined  seam REAR_FASCIA_to_DECK (0.00 mm off skin) 
  FRONT_FENDER_SIDE -> DOOR_UPPER        G0     no line defined  seam FRONT_FENDER_to_DOOR (0.00 mm off skin)
  FRONT_FENDER_TOP -> FRONT_FENDER_SIDE  G1          51.9 deg !  nothing                                     
  HOOD -> FRONT_FENDER_TOP               G2     no line defined  seam HOOD_to_FRONT_BODY (0.00 mm off skin)  
  HOOD -> HEADLIGHT_SURROUND             G1     no line defined  opening HEADLIGHT_HOUSING_L                 
  NOSE -> FRONT_LOWER_INTAKE             G0     no line defined  opening FRONT_MASK                          
  NOSE -> HOOD                           G1     no line defined  nothing                                     
  REAR_DECK -> ENGINE_COVER              G1     no line defined  seam ENGINE_COVER_to_DECK (0.00 mm off skin)
  REAR_FASCIA -> DIFFUSER                G0         73.1 deg ok  seam DIFFUSER_to_FASCIA (0.00 mm off skin)  
  REAR_HAUNCH_SIDE -> DIFFUSER           G1     no line defined  seam DIFFUSER_to_FASCIA (0.00 mm off skin)  
  REAR_HAUNCH_TOP -> BUTTRESS            G0     no line defined  nothing                                     
  REAR_HAUNCH_TOP -> REAR_HAUNCH_SIDE    G1         14.5 deg ok  nothing                                     

  15 of 17 transitions have evidence: a measured crease, a registered panel seam, or a real opening.
  A seam is not a substitute for a class. The class is about the SURFACE; the seam is
  about PANELS. On a real car a G0 break is often a 4 mm gap between two tangent
  panels rather than a crease, so a seam is evidence that the light breaks — but it
  never makes a G1 'satisfied', because a gap is a break and not a transition.

  NO CREASE LINE — the build defines no height table for these, so the angle is
  not measurable. The coverage table above says whether anything else breaks the
  light there; several are satisfied by a panel gap or a real opening instead.
    NOSE -> HOOD
    HOOD -> HEADLIGHT_SURROUND
    NOSE -> FRONT_LOWER_INTAKE
    DOOR_CHANNEL -> SIDE_INTAKE_MOUTH
    REAR_HAUNCH_TOP -> BUTTRESS
    REAR_DECK -> ENGINE_COVER
    ENGINE_COVER -> REAR_FASCIA
    REAR_HAUNCH_SIDE -> DIFFUSER
    FRONT_FENDER_SIDE -> DOOR_UPPER
    DOOR_UPPER -> REAR_HAUNCH_TOP

  'lost' is design minus mesh: how much of the designed turn the built mesh fails to
  show. A NEGATIVE value is not a bonus -- it is faceting. A gentle line sampled every
  38 mm becomes a few flat panels, and the dihedral between two of them can exceed the
  smooth turn it is approximating. The main side line reads 15.9 on the mesh against
  6.5 in the design for exactly that reason.

  It measures only the lines it is told about, and it says nothing about whether a
  line is in the right PLACE — only how hard it breaks.

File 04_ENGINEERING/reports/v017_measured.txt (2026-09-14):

MEASURED ON THE BUILT MESH, v017
  length 4370.0   width 1849.4   body height 876.4 (floor 120 crown 996)
  volume 3.896 m3   faces 8487
  STATEV_WHEEL_F_L [0.0, 732.5, 323.5]
  STATEV_WHEEL_F_R [0.0, -732.5, 323.5]
  STATEV_WHEEL_R_L [-2415.0, 764.0, 337.5]
  STATEV_WHEEL_R_R [-2415.0, -764.0, 337.5]
  wheelbase 2415 track 1465/1528 cowl Z 970 header Z 1255 hoops Z 1235 shut 440/1635

CROWN STATIONS through the rear
   2000:   967.1
   2200:   993.1   step   +25.9
   2400:   989.6   step    -3.5
   2600:   938.2   step   -51.4
   2800:   858.7   step   -79.5
   3000:   760.0   step   -98.7
   3200:   642.6   step  -117.5
   3420:   513.1   step  -129.4

BELTLINE on the built mesh (top of the door at the aperture edge, Y 640..760)
    440: door top   842.6   gap to screen base 970:  127.4
    600: door top   873.9   gap to screen base 970:   96.1
    800: door top   861.4   gap to screen base 970:  108.6
   1000: door top   847.8   gap to screen base 970:  122.2
   1200: door top   845.6   gap to screen base 970:  124.4
   1400: door top   851.4   gap to screen base 970:  118.6
   1600: door top   865.9   gap to screen base 970:  104.1
   1635: door top   873.5   gap to screen base 970:   96.5

MAX WIDTH at the axles (+-260 mm, clear of the arch cut)
  front    1776.1
  rear     1846.8

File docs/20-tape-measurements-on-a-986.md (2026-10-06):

# 20 — Ролетка върху истинска 986 (преди покупката и преди скана)

*2026-10-06. Тези числа отключват предницата и задницата за котиране (v074/v075) и дават отговор на
три допускания в модела. Не трябва да е твоята кола и не трябва скенер — всяка 986 (1997–2004) на
паркинг, в сервиз или при продавач става. Около час с още един човек.*

## Какво ти трябва

Ролетка 5 m, метална линийка 1 m, отвес (конец с тежест) или лазерен нивелир, тебешир или
малярска лента, телефон за снимки. Колата на равен под, гумите напомпани, нищо в багажниците.

## Двете отправни линии — първо тях

1. **Центърът на предното колело** — отвес от центъра на главината до пода, отбележи точката на
   пода с лента. Същото за **задното колело** на същата страна. Измери разстоянието между двете
   точки — трябва да излезе ~2415 mm (публикувано). Ако не излезе, мерете отново: всичко по-долу
   се мери спрямо тези точки.
2. **Подът** е Z = 0. Всички височини се мерят от пода.

## А. Предната греда — отключва P01, P43, сплитерите, ъгловите решетки

Свали предния капак на багажника и погледни отпред под бронята (на 986 гредата е зад пластмасовата
броня, между двата гасителя на удара).

| # | Какво | Как | Какво решава в модела |
|---|---|---|---|
| A1 | Горен ръб на гредата, височина | от пода | дали устата (Z 220..430) минава през нея |
| A2 | Долен ръб на гредата, височина | от пода | същото |
| A3 | Предното лице на гредата — колко е пред центъра на предното колело | отвес от лицето до пода, мери до лентата на колелото | колко дълбока може да е устата (днес до 815 mm пред оста) |
| A4 | Широчина на гредата (ляв до десен край) | линийка | колко широка може да е устата и докъде ъгловите входове |
| A5 | Гасителите: на колко са един от друг и колко са дебели | линийка | проверка на публикуваното 800 mm и дали ъгловите входове ги допират |
| A7 | **Горната опора на предния амортисьор** (гайката в предния багажник): височина от пода, колко е от оста напред/назад, колко е встрани от средата | отвори предния капак | дали прорезът в предния калник (днес до Z 700 при \|Y\| 385..545) минава над нея — днес по мащаба на чертежа тя е при \|Y\| ~500, Z ~736, вътре в прореза |
| A6 | Където са **радиаторите** в ъглите — от/до спрямо центъра на колелото, височина | ролетка | какво хранят ъгловите входове (`docs/13`, отворен въпрос за P43) |

## Б. Задната греда — отключва P21, P22, корпусите на стоповете, перките

Под задната броня, зад ауспуха.

| # | Какво | Как | Какво решава |
|---|---|---|---|
| B1 | Горен и долен ръб на задната греда | от пода | дали прорезът на стопа (Z 593..631), гнездото за номер и тунелът на дифузьора (Z ≤ 410) я пресичат |
| B2 | Задното лице на гредата — колко е зад центъра на задното колело | отвес | колко дълбоки могат да са задните отвори |
| B3 | Широчина на гредата и гасителите | линийка | проверка на публикуваното 824 mm |
| B4 | Ауспухът (заглушителят): размер и място спрямо задното колело, най-ниска точка | ролетка | дифузьорът и двата отвора Ø104 |

## В. Трите допускания, които моделът носи днес

| # | Какво | Как | Какво решава |
|---|---|---|---|
| C1 | Страничното стъкло, вдигнато: колко е навътре от външния ръб на вратата при горния ѝ ръб, отпред до A-колоната | линийка хоризонтално | огледалата (днес главата е на \|Y\| 730..880, допуснато стъкло ~700) |
| C2 | Зад задната линия на вратата: дълбочината на B-колоната (колко е назад от линията, преди да започне плоската ламарина) | отвори вратата, мери | колко дълбока може да е страничната шахта отпред (днес 25 mm) |
| C3 | Зад ламарината пред оригиналния страничен отвор: какво има (канал, колан, кабели) | погледни отвътре през отвора и от купето | дълбочината на шахтата отзад (днес до 130 mm) |
| C4 | Третият стоп на 986: къде е и на каква височина | ролетка | `CHMSL`, днес на капака с 9 mm запас над 850 |

## Как да запишеш

За всяко число: **номерът от таблицата, стойността в mm, и снимка с ролетката в кадър**. Без снимка
числото не се приема — през този проект всяка грешка дойде от мерене (виж паметта на проекта), и
снимката е начинът да се провери второ мерене. Мери всяко число два пъти; ако двете се разминават
с повече от 5 mm, мери трети път.

## Какво правя аз с числата

- A7 → прорезът в калника става по-плитък или се мести навън, над гумата, където може да вентилира арката.
- A1–A5 → обвивка на предната греда в `cage_986.py`, зоната `front crash structure` в
  `manufacturing_audit.py` става точна, `check_donor_fit` пресмята въздуха; устата и ъгловите входове
  се плиткат само колкото трябва (+15–20 mm въздух, твърдо ограничение 3). P01/P43/… се връщат за
  котиране, ако минават.
- B1–B4 → същото отзад.
- C1 → огледалата на истинското място; C2–C3 → дълбочината на шахтата; C4 → третият стоп.

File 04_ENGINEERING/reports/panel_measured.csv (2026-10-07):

ID | PART | PIECES | LENGTH | WIDTH | HEIGHT | AREA_M2 | CORE_VOLUME_CM3 | EST_MASS_KG | FACES
P01 | FRONT_FASCIA | 1 | 295.0 | 1659.2 | 483.0 | 0.726 | 2177.5 | 2.7 | 1485
P28 | FRONT_SPLITTER_L | 1 | 295.0 | 787.4 | 74.0 | 0.045 | 136.0 | 0.17 | 69
P41 | FRONT_SPLITTER_R | 1 | 295.0 | 787.4 | 74.0 | 0.045 | 136.0 | 0.17 | 69
P02 | HOOD | 1 | 1075.0 | 760.0 | 287.5 | 0.861 | 2583.2 | 3.2 | 510
P03 | FRONT_FENDER_L | 1 | 1095.0 | 812.0 | 812.2 | 0.863 | 2589.8 | 3.21 | 788
P04 | FRONT_FENDER_R | 1 | 1095.0 | 812.0 | 812.2 | 0.863 | 2589.8 | 3.21 | 788
P07 | ROCKER_L | 1 | 1807.5 | 135.1 | 206.1 | 0.413 | 1238.8 | 1.54 | 199
P08 | ROCKER_R | 1 | 1807.5 | 135.1 | 206.1 | 0.413 | 1238.8 | 1.54 | 199
P39 | ROCKER_END_L | 1 | 153.8 | 292.7 | 202.5 | 0.038 | 115.4 | 0.14 | 29
P40 | ROCKER_END_R | 1 | 153.8 | 292.7 | 202.5 | 0.038 | 115.4 | 0.14 | 29
P09 | DOOR_SKIN_L | 1 | 1195.0 | 218.0 | 540.1 | 0.881 | 2643.8 | 3.28 | 481
P10 | DOOR_SKIN_R | 1 | 1195.0 | 218.0 | 540.1 | 0.881 | 2643.8 | 3.28 | 481
P11 | SIDE_INTAKE_L | 1 | 366.1 | 56.3 | 370.0 | 0.043 | 128.5 | 0.16 | 88
P12 | SIDE_INTAKE_R | 1 | 366.1 | 56.3 | 370.0 | 0.043 | 128.5 | 0.16 | 88
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

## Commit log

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2026-09-14 Complete the v0.1 package: body envelopes, roof/interior/debug collections, materials, root params
    Adds everything the spec listed that the first pass skipped:
    - 02_BODY envelopes: front clamshell, hood, front fenders, door skins, rear haunches, rear deck
    - 00_DONOR_HARDPOINTS (pointer to CAGE_986, not a duplicate), 06_ROOF (two PROVISIONAL
    envelopes flagged do_not_trust), 07_INTERIOR (seat centrelines), 99_DEBUG (dimension
    guides with labels, worst-case steering sweep)
    - six viewport materials, STATEV_001_ROOT empty with 26 parametric properties
    - rear lights rebuilt as an L (horizontal + vertical arms) instead of a plain box
    - incremental save 02_DESIGN/exterior/STATEV_001_v001.blend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
    [STATEV_001_v001.blend]
2026-09-14 Close the last gaps against the spec: naming, ET params, intake volumes, materials, cameras, warnings
    - STATEV_ prefix on every object; sections are STATEV_S00..S14 with role as a property
    - wheel rim/ET exposed as PROVISIONAL design parameters (§5)
    - side intake split into INLET (donor opening, derived) + DUCT + OUTLET (provisional) (§15)
    - materials assigned to objects, not just created (§26)
    - five diagnostic cameras, engine-bay and roll-hoop clearance envelopes (§30)
    - ten STATEV_WARN_* objects with text labels, recomputed on every run so a corrected
    number removes its own marker (§30 "warning objects when intersections occur")
    - seventh diffuser fin to match the FIN_01..07 list (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
    [STATEV_001_v001.blend]
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2026-09-14 Second iteration: take the design decisions on the CAD side, stop asking for numbers
    Priority order applied: donor hardpoints > clearance > proportions > surface continuity >
    airflow > manufacturability > provisional dimensions. Six decisions recorded in DECISIONS:
    - headlight: the 650x100x65 bar is gone. Split into a thin DRL blade whose Z is solved from
    the sections so it lies on the body's widest line, and a cavity sized for a real Hella
    90 mm bi-LED module. Lit-surface lower edge 515 mm, legal.
    - side intake: channel extended to specX 2080, the donor's real opening
    - arches: smooth cosine widening around each axle (+18 front, +34 rear) instead of hand-tuning
    individual sections; t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
    [STATEV_001_v003.blend]
2026-09-14 Add a preview loft so the proportions can be judged; it found three real errors
    The diagnostic set was boxes. You cannot answer "does this read as STATEV 001" from boxes, so
    statev_preview_loft.py lofts a preview skin through the master sections and cuts the cabin
    aperture. Not a body surface, not manufacturing geometry — proportion review only.
    Building the form exposed three things the section tables alone had hidden:
    - overall width came out 1906, not the 1850 target: the axle widening added 56 mm
    - the deck crown was my own invention and inflated the tail to 1096; it is now clamped to the
    spec's deck spine and the top sits at 910
    - the wheel arches were built as constant-Y arcs. The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
    [STATEV_001_v003.blend]
2026-09-14 Fix a silent crash that had been building half the scene, and run a QC sweep
    statev_skeleton.py raised StopIteration on next(b for b in BOXES if b[0] == "HEADLIGHT") — that
    element was renamed to PROJECTOR three commits ago. The exception killed the build partway, so
    the root object, cameras, materials and debug layer were never created and the last .blend saves
    were incomplete. Element lookup now returns None and the dependent warning simply does not fire.
    QC sweep after the fix: all three scripts run clean, 133 objects, no duplicate names, preview
    mesh has zero non-manifold edges and zero zero-area faces, the DRL blade does not intersect the
    projector cavity, blade sits at Z 350-545 aga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
    [STATEV_001_v003.blend]
2026-09-14 Align the spec with the new reference render: raised deck, buttresses, tail bar, hood vents
    The owner supplied a more developed infographic with a donor-overlay panel and a roof-mechanism
    compatibility strip. Four things in it contradict the written spec, resolved in the render's favour:
    - DECK_SPINE moved from specX 1450 (over the seats) to 1760 (the hoop plane) and raised from
    Z 800 to 960. At 800 the project's own decision, that the closed roof meets the deck in one
    line, is impossible against a windshield header at 1255.
    - AERO_FIN replaced by BUTTRESS: neither render has free-standing fins, both show raised
    shoulders with the louvred deck sunk between them. Y +-600 sits near the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
    [STATEV_001_v004.blend]
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2026-09-14 Take in the surface behaviour spec, and run its own test on the preview — it fails, as it should
    Seventeen zones encoded as data: curvature, where the highlight runs, where the surface is tense,
    which edges stay sharp, how each meets its neighbour, and the mistake to avoid in that zone. Plus
    a sixteen-entry continuity map (G0 structural break, G1 character transition, G2 main body) with
    the rule that G2 is not chased everywhere, which is what makes CAD models look like soap.
    The critical rule is that the skin is a network of patches, not one global loft through the
    sections. statev_preview_loft.py is exactly one global loft, so it breaks the rule by
    construction. That is acceptable only b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
    [STATEV_001_v006.blend]
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2026-09-14 Stage 01: build the master exterior volumes with the negative spaces cut for real
    Replaces statev_preview_loft.py, which was the single global loft the surface spec forbids and
    which failed its own highlight test. This builds per-zone volumes into STATEV_MASTER with the
    five void families cut as actual geometry: cabin aperture, four wheel arches, the channels behind
    the front wheels, the door channel running into the side intake, and the rear undercut. Their
    absence is exactly why the preview read as a balloon.
    Volume 4.629 -> 3.826 m3, 2294 faces, split 1019/504/771 across front, side and rear.
    Three bugs had to be found to get here, all recorded in docs/17:
    - scripts read each other by c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
    [STATEV_001_v007.blend]
2026-09-14 SURFACE_LOCK_01 first pass: fix five parametric bugs, and name the five that are not bugs
    FIXED, all of them defects in my own parametric build rather than styling choices:
    - the crown stepped 170 mm in one millimetre at the cowl, because HOOD_SPINE ends at specX 420 and
    DECK_SPINE starts at 1760 with a fallback in between. That was the largest kink in the profile
    and it sat exactly where the shoulder line crosses. The three now blend with smoothstep.
    - zone_shape switched character with if/elif at specX 340 and 1900, putting a step in the surface
    at both. All three characters are now evaluated and mixed over a 420 mm band.
    - faceting is fixed in the control data, not with a smooth mod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
    [STATEV_001_v008.blend, STATEV_001_v009.blend]
2026-09-14 Sculpt the five character elements as parametric fields, not by hand
    I was too categorical last time in calling these manual-only work. Four of the five are expressible
    as fields over the body, and the fifth is one number in the buttress loft. Doing it this way means
    a note like "the shoulder should rise 200 mm later" is a number change rather than a remodel.
    - main side line: a 13-point (specX, Z) trajectory from nose to tail with a local half-width gain
    of 13 mm at the line, falling off over 42 mm below and 95 mm above. The tight lower falloff is
    what makes it read as a crease instead of a bulge.
    - front fender shoulder: a 20 mm gaussian centred on the front axle, 470 wide in X and 12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
    [STATEV_001_v010.blend]
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2026-09-14 Four approved corrections: nose mouth, rear flank, rocker edge, and width back to 1850
    1. The front mouth is now a real void. NOSE_MOUTH was in the element list but never in the cutter
    families, which is why the nose came out as a solid rounded prow. Six stations, specX -965 to
    -655, up to 210 mm deep, Z 195..410. The nose was not rounded off to compensate.
    2. Rear flank: a new flank() field pulls the profile toward the station maximum across Z 300..660
    between specX 1900 and 3050, turning the rolling arc into a near-vertical wall with the
    undercut beneath it.
    3. Rocker: tuck 30 -> 34 mm and the transition 55 -> 18 mm. The short run is what makes it an edge
    rather than a dent.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
    [STATEV_001_v011.blend]
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2026-09-14 Primary surfaces iteration 2: find the cause of the "separate plate" rear and fix the flat mid-side
    The rear deck read as a plate sitting on the car because of one line: crown = max(crown, z_top+10).
    The rear sections carry a control point at Z 900 while the deck spine asks for 880, so the max won
    and forced a flat 910 roof across the whole rear regardless of the spine. Behind the hoops the
    spine now governs: section points above it are dropped and the crown follows the line, so the rear
    falls into the fenders instead of capping them.
    The flat mid-side came from the profile being essentially straight between the wheels. BELT_DIP
    lowers the crown by up to 48 mm, centred at specX 1050 and eas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
    [STATEV_001_v014.blend]
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2026-09-14 Geometry correction: haunch peak and tail fall fixed, front widened, and one fault I mis-diagnosed
    Rear haunch peak moved from specX 2000 to 2400 — 15 mm from the rear axle instead of 415 mm ahead
    of it. The buttress rise is now a gaussian centred on the axle rather than a sine that topped out
    early, so the mass sits over the tyre rather than over the seats.
    Tail now falls monotonically: 625, 570, 557, 513 at specX 3050/3200/3300/3420. DECK_SPINE was
    extended to 3420 so the fallback crown can no longer lift the last station by 106 mm.
    Front width at the axle +24 mm to 1773.7 via a taller, wider fender field (gain 34 -> 52, centred
    at Z 600 with a 180 band) so there is real volume above t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
    [STATEV_001_v015.blend]
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2026-09-14 v016 architecture correction: voids made real, rear crown made continuous, beltline lifted
    Priority 1, negative spaces. The root cause was real: cutters were sized from the raw section
    profile while the body is built from the shaped profile. They now sample the built ring at the
    centre of the band, and depth is measured as pull-in against the shoulders either side rather than
    by trusting a boolean reported success. Front wheel channel 0 -> 128 mm, side intake mouth
    0 -> 84 mm, rear undercut 106 -> 193 mm.
    Priority 2, rear crown. The 201 mm step at specX 2800 is gone; the largest step is now 77 mm at
    the tail. The buttress is no longer a separate mass unioned onto the skin — it is part of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
    [STATEV_001_v016.blend]
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2026-09-14 v017: the side line, the beltline and the voids rebuilt as fields instead of booleans
    The door channel failed four times as a boolean. It is now part of the section profile, the way
    the rear buttress was fixed in v016, and it is one field from the trailing edge of the front arch
    to the intake mouth rather than two channels that met. Measured as chord depth — how far the
    surface sits inside the line joining its own shoulders — v016 was negative almost everywhere, that
    is, bulging outward where the channel was meant to be. v017 runs 50 to 85 mm with a largest
    station-to-station change of 6 mm through the door.
    Two causes, both real. The cutters were sized outboard of a surface that the ch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
    [STATEV_001_v017.blend]
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2026-09-15 v018: halve the unapproved fender rise, sharpen the deck edge, fix the nose cutter — and correct two of my own diagnoses
    Front fender. Six parameter tests before choosing anything, each measured with the X-smoothing that
    build() applies, because ring() alone does not predict the built surface — which is precisely how
    this fault entered v017. CABIN_X0 and CABIN_RAMP move the fender top and the door top together at
    close to 1:1; the smoothing couples them and no setting separates them. Giving BELT_Z an explicit
    low value at specX 345 does separate them, and it saturates: two tests 15 mm apart in that value
    produce identical geometry, because below about 755 the shelf drops under the sectio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
    [STATEV_001_v018.blend]
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2026-09-15 v019 becomes the baseline, and the supplier questionnaire learns that there are two suppliers
    The undercut release lands at xb = 2950, chosen from a controlled A/B/C run on the exact v018
    baseline where xb was the only parameter that differed. 3050 changed too little to be worth doing;
    2850 released too fast, 58 mm between adjacent stations against 50 in v018 itself. The value is a
    visual selection and the report says so in as many words, because the only measurable anchors in
    that region are the rear arch ending at specX 2780 and the diffuser starting at 3145, and all three
    candidates sat between them. The peak is untouched at 287.3 mm on specX 2870; only the release
    moved, and the largest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
    [STATEV_001_v019.blend]
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2026-09-15 Decide the four open questions: two deviations accepted, a partial checkpoint, eleven parts added
    The deviations are accepted as working lines rather than frozen values, and on measured grounds.
    Lowering the front fender through the existing architecture bottoms out at 730 mm, not the 715 that
    was asked for, and reaching even that costs 64 mm at the A-pillar for 33 mm of fender — an exchange
    rate of one to two in the wrong direction. The A/B also showed the transition from fender to
    A-pillar stops flowing and becomes a step. The proposed local fender_top field is deliberately not
    written: it would be the right way to separate the two lines, but the test said a lower fender looks
    worse, so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
    [panel_architecture.csv]
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2026-09-16 Withdraw yesterday's millimetres, fix the audit's arch claim, and prove the rocker
    Three corrections and one reclassification, all from the same measurement.
    First, the numbers committed a few hours ago are withdrawn. boundary_sensitivity.py moved each
    approximate donor value by 25 mm and reported how far a panel's extent changed: 28.0 mm for the
    hood, 42.5 for the front fender. Sweeping the perturbation disproves them. P15 reports 60.1 mm at a
    2 mm perturbation and 60.1 mm at 40; P02 reports 28.0 at 2 and 28.0 at 25. Two millimetres cannot
    push an edge sixty. What moves is which mesh station is the panel's outermost, and the blockout's
    longitudinal stations near those lines sit 36 to 75 mm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
    [donor_exposure.csv, manufacturing_audit.csv]
2026-09-16 The exterior skin was never 16.99 m2. It is 11.52, and one face was a third of the error
    A face-size audit of the panel map found nine faces larger than 0.05 m2 passing not_panel() and
    being counted as exterior skin, 3.95 m2 of a reported 16.99. The worst was a single four-vertex
    quad of 1.876 m2 lying flat at Z 640 across the whole cabin aperture: the floor of the cabin cut,
    assigned to P09 DOOR_SKIN, and by itself half of that panel's reported area.
    The cause is plain enough that it explains why it lasted. All three rules in not_panel screen on
    ny, so a boolean cap whose normal runs along X or Z passes them untouched however large it is, and
    nothing downstream ever looks at the size of a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
    [P28_FRONT_SPLITTER_core_PROVISIONAL.stl, donor_exposure.csv, manufacturing_audit.csv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]
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2026-09-16 Measure parts instead of regions, mirror the right halves, and hand the supplier one file
    Three corrections and one new output, all from following the pairs through.
    panel_extract was measuring regions and calling them parts. The map answers under one id for both
    sides of the car, so a mirrored region is two parts wearing one name, and measured that way the
    rocker came out 0.888 m2 and 1841 mm wide -- the pair -- in a table headed "per part" that feeds a
    document meant for a supplier. Each part is now cut out on its own side: the rocker is 0.445 m2 and
    269 mm. Total skin rises from 11.518 to 11.565 m2, because the right splitter now carries the
    0.043 m2 its own extraction was losing.
    The r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
    [P08_ROCKER_R_core_PROVISIONAL.stl, P40_ROCKER_END_R_core_PROVISIONAL.stl, P41_FRONT_SPLITTER_R_core_PROVISIONAL.stl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]
2026-09-16 Cut on the boundaries before assigning, and find 28 install vectors pointing the wrong way
    Until now the panel map assigned a whole face by where its centre fell. On a mesh whose tessellation
    is not itself mirror-symmetric that produces panels which are not mirror-symmetric either: P28 and
    P41 came out 0.142 and 0.099 m2, and P01's area-weighted centroid sat 65 mm off the centreline.
    Measured by volume in spec-X bands -- volume being the one instrument here that does not care about
    tessellation -- the body is symmetric to 0.2 litres, all of it in the nose. The shape was never
    asymmetric. The assignment was.
    So the body is now cut on every plane panel_of switches on before anything is assign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
    [P01_FRONT_FASCIA_core_PROVISIONAL.stl, P07_ROCKER_L_core_PROVISIONAL.stl, P08_ROCKER_R_core_PROVISIONAL.stl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]
2026-09-16 Turn the blanks into decisions and cut the nine proven panels into 125 printable sections
    Every step of this chain has been stopping at a None and naming the docs/13 question behind it. That
    was right while the questions were open and it is wrong now, because it stops the work. So the blanks
    become decisions, kept in one block with the argument for each, and each one edit away from the
    shop's real answer.
    The wall stays 3.0 mm: the print is the core and the glass carries the part, so the wall only has to
    stay rigid over a 350 mm span without spending filament on 11.5 m2 of car. The flange is 30 mm with a
    1 mm bond line, which is the ordinary one-off lap -- enough area for the joint to be st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
    [P01_FRONT_FASCIA_s01.stl, P01_FRONT_FASCIA_s02.stl, P01_FRONT_FASCIA_s03.stl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]
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2026-09-16 v022: check the donor fit against the body that exists, and fix three things it found
    check_statev_vs_donor.py reads SECTIONS and PACKAGE out of the skeleton and compares those numbers
    with the 986. That was right when there was only a skeleton and it is wrong now, in the way this
    project has been wrong before: a number taken from the INPUT to a loft is not a fact about its
    OUTPUT. Five of the character features -- the side line, the fender crest, the rocker, the flank, the
    buttress -- exist only as fields applied after the sections, so the spec-side check cannot see them.
    It still reports that the fender does not crown the front wheel; the built body has crowned it since
    v021.
    check_donor_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
    [P01_FRONT_FASCIA_core_PROVISIONAL.stl, P01_FRONT_FASCIA_s01.stl, P01_FRONT_FASCIA_s02.stl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]
2026-09-17 v023: find where the balloon actually is, and give the front the flank the rear has had since day one
    The highlight test said MIXED at 0.31 without saying where, so the next thing was to break it down by
    X zone against Z band. It localises immediately. The front fender is poor in every band -- 0.47, 0.49,
    0.40, 0.54, 0.23 -- and worst at Z 660 to 800, the shoulder between the flank and the crest added in
    v021. The rear haunch on the same bands reads 0.36, 0.30, 0.22, 0.47, 0.37 and the door channel gets
    down to 0.12.
    The reason is in this file's own history. The rear got flank() on 2026-09-14, described there as the
    fix for a haunch that "read as a bulge" because every section was a smooth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
    [P01_FRONT_FASCIA_core_PROVISIONAL.stl, P01_FRONT_FASCIA_s01.stl, P01_FRONT_FASCIA_s02.stl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]
2026-09-17 The owner is right: the shapes are not the render's, and the reason is structural
    Two things were checked before answering. First, whether it was only shading: the geometry does carry
    2047 edges over 30 degrees, but every face was shade-smooth, which averages normals across them and
    rounds every crease. Auto smooth at 28 degrees is now applied. It is slightly crisper and it was not
    the problem.
    The second is the real one. The body is ONE closed lofted volume built from fifteen cross-sections
    plus scalar fields. The render is layered panels with air between them, which is what CLAUDE.md's own
    design direction says in as many words: layered panels with negative space, floating fenders, thin
    l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
    [EXPERIMENT_undercut_xb2850_UNAPPROVED.blend, EXPERIMENT_undercut_xb2950_UNAPPROVED.blend, EXPERIMENT_undercut_xb3050_UNAPPROVED.blend]
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2026-09-17 Three versions shipped without measuring the goal. Here is what broke, and the code that stops it
    v024, v025 and v026 passed only the bookkeeping checks: the map closes, the locked values held,
    packaging and lighting were clean. The silhouette overlay against ref-05 and the curvature test were
    not run once across all three. That is precisely the failure the owner named -- measuring what is
    easy instead of what matters.
    Run now, against what was actually built, the front had regressed from 3 mm to 21, worst 81.
    Two causes. The fender channel liner stood 75 to 109 mm PROUD of the body. Its top was written as a
    fixed Z 974 while the crown there is 865 to 899, so it was a fin sticking out of t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
    [P01_FRONT_FASCIA_core_PROVISIONAL.stl, P01_FRONT_FASCIA_s01.stl, P01_FRONT_FASCIA_s02.stl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]
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2026-09-17 v029: fix the plan, 5.9% to 2.3% — after withdrawing my own result for normalising on the mirrors
    The first plan table had a spike of 1.000 at 39% of the length, alone between 0.862 and 0.849. No
    car's shape does that. Checked in fine steps it runs 37 to 41%, five stations, rising 137 px to 159
    and dropping straight back to 135 -- a discrete object about 220 mm long standing 140 mm proud. Those
    are the door mirrors, and our car has none: P37 and P38 are BLOCKED because the skeleton carries no
    mirror envelope at all.
    So every station on our side had been divided by a number 18% larger than the body's true maximum,
    and "the middle is too full" was half an artefact of that. The 36 to 42% ban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
    [P01_FRONT_FASCIA_core_PROVISIONAL.stl, P01_FRONT_FASCIA_s01.stl, P01_FRONT_FASCIA_s02.stl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]
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2026-09-21 v031: the nine panel seams did not lie on the car, and now cannot stop lying on it
    Measured them against the built skin for the first time — they were written by hand on
    14 September from the reference and never checked since, while the surface moved through
    v017 to v030. Every one is off it: 25 to 152 mm on average, 210 mm at worst. The worst,
    DIFFUSER_to_FASCIA, was three points on a straight line at Z 330 running through the
    INSIDE of the solid, because a line across the car at one height and one station does not
    touch the surface at all — it passes through it.
    What was actually wrong is narrower than "the seams are wrong". Their PLANES are right and
    are the panel boundaries: panel_m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
    [STATEV_001_v031.blend]
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2026-09-21 check_docs.py: the prose was never checked against the filesystem either
    Code has check_goal, check_reports and the freeze rule. The documents that tell you what to
    run had nothing, and that is exactly where two findings came from: the three orphan reports
    on 21 September, where CLAUDE.md named a script as "the output of" a file no script wrote,
    and the reverse on 16 September, where CLAUDE.md named ref-07 and ref-08 as the visual
    authority and neither image was in the repo.
    It checks every backticked path in CLAUDE.md and docs/*.md. Five of the first findings were
    faults in my matcher rather than in the documents and were fixed before reporting any of
    them: {persp,top,front} is brace expan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
    [donor_exposure.csv]
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

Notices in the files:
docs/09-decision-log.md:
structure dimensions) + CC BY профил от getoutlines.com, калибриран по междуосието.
